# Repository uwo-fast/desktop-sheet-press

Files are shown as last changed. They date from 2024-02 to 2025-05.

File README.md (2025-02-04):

# Open Source Scientific Sheet Press: General Overview

This repository contains the design assets for the publication [Open-source cold and hot scientific sheet press for investigating polymer-based material properties](https://doi.org/10.1016/j.ohx.2024.e00566), which details the development of an adaptable, open-source platform for polymer sheet pressing.".

## Description

The Open Source Scientific Sheet Press is a mechanical device engineered for converting plastic waste into flat sheets of recycled plastic. Drawing inspiration from existing models like Precious Plastics, this platform is designed with adaptability, flexibility, and sustainability as core principles. This repository contains the main resources for the design of the physical press and it's manufacturing.

## Key Features

1. **Adaptability**: Engineered to work with a diverse range of plastic materials.
2. **Scalability**: Modular design allows for easy scaling to meet various production needs.
3. **Flexibility**: Utilizes open-source and off-the-shelf components, with comprehensive documentation and multiple system topologies for customization.

## General Applications

1. **Material Recycling**: Transforms plastic waste into reusable sheets.
2. **Product Manufacturing**: Ideal for the production of flat plastic components across various applications.
3. **Research and Development**: Serves as a testbed for material properties and novel production methods.

## Future Directions

1. **5x5' Canadian Standardized Sheet Press**: This version will meet industrial standards within the province of Ontario.
2. **Expanding System Topologies**: Work is ongoing to offer more system variations based on desired specifications and features.
3. **Vacuum Forming Integration**: Plans to incorporate vacuum forming capabilities, expanding the range of products that can be manufactured from the recycled plastic sheets.
4. **Automation and Industry 4.0**: Future iterations will focus on integrating smart technologies for autonomous operation, real-time data analytics, and IoT capabilities.
5. **Comprehensive Sourcing**: Plans to provide sourcing information tailored to various locales, considering regional regulations, standards, and availability.
6. **Reengineering High-Cost Components**: Long-term goal to redesign non-open-source and expensive components to meet required standards and certifications.

## Repository Structure

This repository will include multiple iterations and variations of the sheet press, acting as a living document for continuous development and enhancements.

For detailed documentation, consult the respective folders and files within this repository.

## About the FAST Research Group

The Free Appropriate Sustainable Technology (FAST) research group, led by Professor Joshua Pearce, is based at Western University and focuses on driving sustainability innovations. The group works on a myriad of projects ranging from solar photovoltaic technology to alternative food to open-source hardware to distributed recycling and additive manufacturing (DRAM).

This Open Source Sheet Press project is an initiative led by the FAST group, aligning with our broader goals of sustainable development and open-source technology. We are focused on developing solutions that not only contribute to recycling and sustainable manufacturing but also push the boundaries of what's possible through continuous research and innovation.

For more information on the FAST group, please visit [FAST on Appropedia](https://www.appropedia.org/FAST).

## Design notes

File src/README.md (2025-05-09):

# software

The main current functional software can be found in 'main' folder, see 'command_usage.md' and/or 'gui_usage' under the main 'docs' folder for operation instructions.

## Overview

Dual channel PID temperature controller. Can be operated as two independent loops or cascaded.

## Important Notes

### Safeguard against NaN

Safeguard against NaN (Not a Number) outputs from PID controllers, which can occur if the temperature sensor provides invalid readings. This occurs every once in a while with the MAX31855 thermocouple amplifier.If the PID output is NaN, perform a bumpless reset by:

1. Switching the PID controller to MANUAL mode to halt automatic control.
2. Resetting the output to 0 to ensure no erroneous signals are sent to actuators.
3. Switching back to AUTOMATIC mode to reinitialize the PID controller's internal state.

This prevents the NaN value from persisting and propagating through subsequent control cycles.

### Generic Software Work

Currently the software from this project is no longer under development and future development efforts are being continued at [uwo-fast/OpenTempControl](https://github.com/uwo-fast/OpenTempControl)

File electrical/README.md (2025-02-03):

# Electrical

## Attribution

https://github.com/adafruit/MicroSD-breakout-board

https://github.com/botbotty/Nano_KiCAD

https://github.com/adafruit/Adafruit-MAX31855-breakout-board

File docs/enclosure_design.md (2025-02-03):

# Electrical Enclosure CAD

THe CAD for the electrical enclosure was made using Onshape by Morgan C. Woods: [Electrical Enclosure - Desktop Sheet Press](https://cad.onshape.com/documents/9d69c9f84549b53a6491ef35/w/14b6a93e6542961346169c7c/e/4beb3684347d9fde3d54fadf).

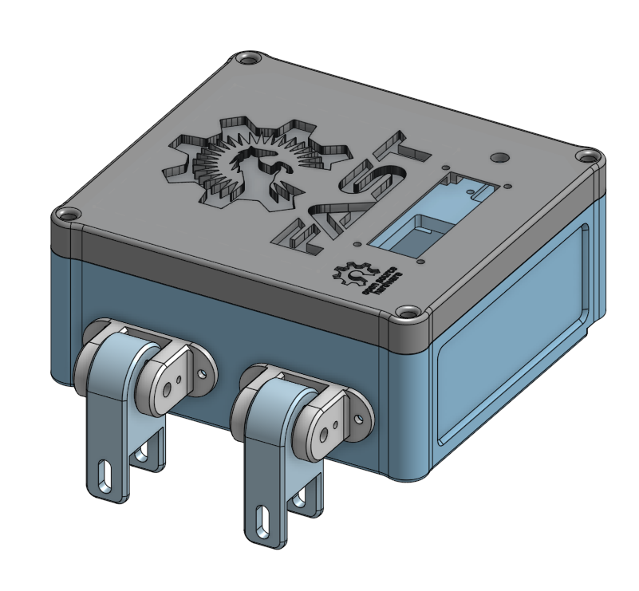
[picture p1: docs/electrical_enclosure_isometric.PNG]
Isometric View of the Electrical Enclosure

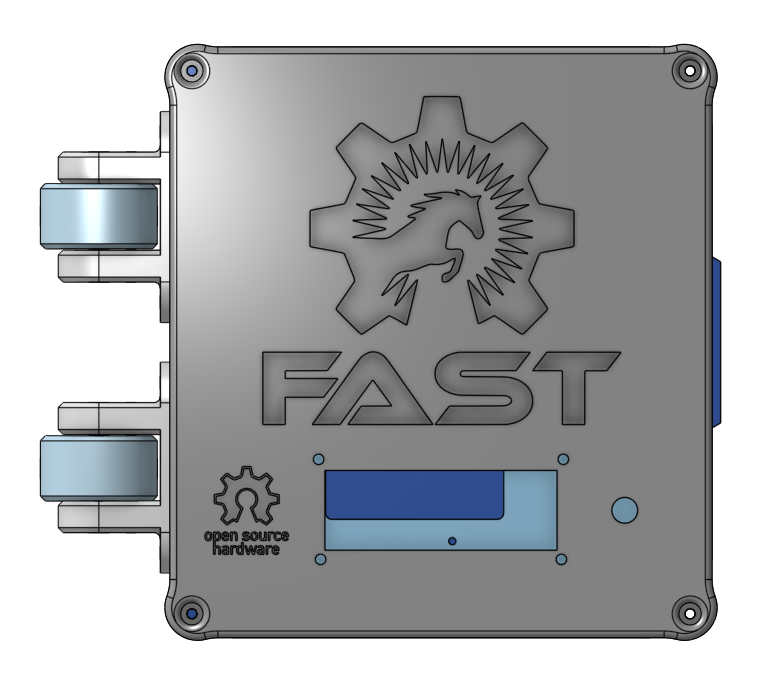
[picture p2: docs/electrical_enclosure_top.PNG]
Top View of the Electrical Enclosure


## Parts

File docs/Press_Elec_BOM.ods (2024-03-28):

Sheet: Paper_Rev0
 |  |  |  | Total | $880.58 | Tot. - RE | $375.38
Item # | Component Designator | Description | Number | Cost per unit CAD | Total cost CAD | Source of materials | Material type
36 | Flat Heating Element | 125W, 120V, Steel Strip Heater | 8.00 | $63.15 | $505.20 | Omega (https://www.omega.ca/en/industrial-heaters/strip-heaters/msh/p/MSH00007) | Rust-resistance Steel, Mica Insulation
37 | Arduino Nano | Nano V3.0 R3 Microcontroller Board | 0.33 | $39.99 | $13.33 | Amazon (https://www.amazon.ca/ELEGOO-Arduino-ATmega328P-Without-Compatible/dp/B0713XK923/) | Electronics
38 | Thermocouple sensor | Fine Diameter Thermocouple Probes | 2.00 | $50.97 | $101.94 | Omega (https://www.omega.ca/en/temperature-measurement/temperature-probes/probes-with-lead-wires/fast-mi-tc/p/TJM-CA310-M100U-150) | 310 Stainless Steel, PFA Insulation
39 | Thermocouple amplifier | MAX31855 Break out | 2.00 | $14.95 | $29.90 | Adafruit (https://www.adafruit.com/product/269) | Electronics
40 | Solid State Relay | SSR RELAY SPST-NO 10A 24-280V | 2.00 | $30.04 | $60.08 | Digikey (https://www.digikey.ca/en/products/detail/altran-magnetics-llc/ASR-SIM240D10ZW-LQ/14553491) | Silicon, epoxy, aluminum
41 | Hook-up Wire | 14 AWG, 100ft Wire | 0.50 | $72.55 | $36.28 | Mouser (https://www.mouser.ca/ProductDetail/Alpha-Wire/541419-GR005?qs=G7mWZQZ8fQl1gNz6Gz27bw%3D%3D) | Copper, PVC
42 | Male Blade Terminal | Terminals 16-14 Nylon Insulated Male Quick Connect | 10.00 | $0.15 | $1.50 | Mouser (https://www.mouser.ca/ProductDetail/Mueller-Electric/AI-50181N?qs=rQFj71Wb1eWmiZF%252BkWw8Ig%3D%3D) | Tin-plated Brass, Nylon
43 | Female Blade Terminal | Terminals 16-14 Fully Nylon Insulated Female Quick Connect | 10.00 | $0.15 | $1.53 | Mouser (https://www.mouser.ca/ProductDetail/Mueller-Electric/AI-50209?qs=rQFj71Wb1eUSkyk1RbYImw%3D%3D) | Tin-plated Brass, Nylon
44 | High-Temperature Hook-up Wire | High-Temperature Stranded Wire with Fiberglass Outer and Mica Inner Insulation, 18 Gauge; Length, ft. 50 | 0.20 | $85.50 | $17.10 | McMaster (https://www.mcmaster.com/heater-wire/maximum-temperature~840-f/) | Tin-plated Copper, Fiberglass, Mica, PTFE
45 | Circuit Breaker | Mode: W28-XQ1A-14, 14A, Thermal type Circuit Breaker | 1.00 | $7.44 | $7.44 | Digikey (https://www.digikey.ca/en/products/detail/te-connectivity-potter-brumfield-relays/W28-XQ1A-14/1128430) | Copper/Silver, Thermoset Polymer
46 | Metric Screws & Nuts | VIGRUE 1080Pcs Metric Socket Head Screws, Bolts, Nuts, Washers Kit | 0.02 | $29.00 | $0.54 | Amazon (https://www.amazon.ca/VIGRUE-M2-M3-M4-1080PCS-Stainless-Screws-Socket/dp/B07FCDL2SY/) | Alloy Steel
47 | AC Power Cord | 14AWG NEMA5-15P - IEC320 3' Power Cord | 1.00 | $12.91 | $12.91 | Digikey (https://www.digikey.ca/en/products/detail/tripp-lite/P007-003/5359145) | Copper, PVC
48 | Power Entry Recipticle | AC Power Entry Modules IEC-320 C-14 | 1.00 | $16.59 | $16.59 | Mouser (https://www.mouser.ca/ProductDetail/TE-Connectivity-PB/15CE1?qs=4aYpRZv1C8L8%2FzM5tPK%252BSA%3D%3D) | Copper/Silver, Thermoset Polymer
49 | Jumper Wires | 120pcs Multicolored Dupont Wire 40pin | 0.13 | $15.99 | $2.00 | Amazon (https://www.amazon.ca/Elegoo-120pcs-Multicolored-Breadboard-arduino/dp/B01EV70C78/) | Copper, PVC, ABS
50 | LCD Display | SunFounder IIC/I2C/TWI 1602 Serial LCD | 1.00 | $13.59 | $13.59 | Amazon (https://www.amazon.ca/SunFounder-Serial-Module-Display-Arduino/dp/B019K5X53O/?th=1) | Electronics
51 | Rotary Encoder Dial | Model KY-040, 5V, 20 PPR Rotary Encoder Dial | 0.20 | $17.40 | $3.48 | Amazon (https://www.amazon.ca/Cylewet-Encoder-15%C3%9716-5-Arduino-CLT1062/dp/B07DFFSZ73) | Electronics
52 | AC/DC Converter | PSK-5D-9 – AC/DC Module | 1.00 | $9.80 | $9.80 | Mouser (https://www.mouser.ca/ProductDetail/CUI-Inc/PSK-5D-9?qs=DRkmTr78QAS7xBfnsfADZA%3D%3D) | Electronics
53 | SD Card | SAMSUNG EVO Select Micro SD-Memory-Card | 1.00 | $20.05 | $20.05 | Amazon (https://www.amazon.ca/SAMSUNG-Plus-128GB-MB-ME128KA-AM/dp/B09B1JFY24?th=1) | Electronics
54 | SD Card Reader | Adafruit MicroSD breakout board PCB | 1.00 | $10.68 | $10.68 | Digi Key (https://www.digikey.ca/en/products/detail/adafruit-industries-llc/254/5761230) | Electronics
55 | Wire Splice Connector | TE Connectivity Electro Tap Connetor 1-to-2 wire splitter | 2.00 | $1.28 | $2.56 | Mouser (https://www.mouser.ca/ProductDetail/TE-Connectivity/735398?qs=sd1rtLGwt44IW6QwNSGZLw%3D%3D) | Electronics
56 | Tie Plate | Simpson Strong-Tie TP 3-1/8-in x 5-in 20-Gauge Galvanized Tie Plate | 1.00 | $2.49 | $2.49 | Lowes (https://www.lowes.ca/product/straps-ties/simpson-strong-tie-tp-3-18-in-x-5-in-20-gauge-galvanized-tie-plate-94135) | Galvanized Steel
57 | PETG Filament | Polymaker PETG Filament 1.75mm, ]1kg | 0.40 | $28.99 | $11.60 | Amazon (https://www.amazon.ca/Polymaker-Filament-1-75mm-Strong-Printer/dp/B0CB8C891M/?th=1) | Galvanized Steel
58 |  |  |  |  | $0.00
59 |  |  |  |  | $0.00

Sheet: v3
Bill of materials |  |  | Project name: | RH Mini Press
Part # | Common Name | Product Name | Number of products to buy | Cost/Product | Total Cost | URL | Special instructions | Ordered | Received | Set
1 | Braided Sleeving | Techflex® Insultherm® Tru-Fit Braided Fiberglass Sleeving | 0.12 | 64.66 | 7.7592 | https://www.cabletiesandmore.ca/insultherm-tru-fit-sleeving | 3/8" dia, 50' long | 1 | 0 | 0
2 | Thermocouple Temperature Sensor | 240-080 – THERMOCOUPLE WIRE K-TYPE 1M | 4 | 15.63 | 62.52 | https://www.digikey.ca/en/products/detail/digilent-inc/240-080/5418219 |  | 1 | 1 | 0
3 | Solid State Relay | SSR: ASR-SIM240D25RW-LQ | 2 | 29.1 | 58.2 | https://www.digikey.ca/en/products/detail/altran-magnetics-llc/ASR-SIM240D25RW-LQ/14553471 |  | 1 | 1 | 0
4 | Power Entry Recipticle | AC Power Entry Modules IEC-320 C-14 | 1 | 16.59 | 16.59 | https://www.mouser.ca/ProductDetail/TE-Connectivity-PB/15CE1?qs=4aYpRZv1C8L8%2FzM5tPK%252BSA%3D%3D |  | 1 | 1 | 0
5 | Heat Sink | ???? | 2 | 1.31 | 2.62 | https://www.mouser.ca/ProductDetail/CUI-Devices/HSB24-252510?qs=t7xnP681wgWWLZ01VB4mNg%3D%3D |  | 1 | 1 | 0
6 | Wire | Hook-up Wire 541419 GREEN 100 FT | 1 | 72.55 | 72.55 | https://www.mouser.ca/ProductDetail/Alpha-Wire/541419-GR005?qs=G7mWZQZ8fQl1gNz6Gz27bw%3D%3D |  | 1 | 1 | 0
7 | I2C Converter | LCD Display I2C Interface | 1 | 2.47 | 2.47 | https://www.pcboard.ca/iic-i2c-serial-interface-for-lcd |  | 1 | 1 | 0
8 | Male Blade Terminal | Terminals 16-14 Nylon Insulated .250 X 0.032 Male Quick Connect | 10 | 0.15 | 1.5 | https://www.mouser.ca/ProductDetail/Mueller-Electric/AI-50181N?qs=rQFj71Wb1eWmiZF%252BkWw8Ig%3D%3D |  | 1 | 1 | 0
9 | Female Blade Terminal | Terminals 16-14 Fully Nylon Insulated .250 X 0.032 Female Quick Conn | 10 | 0.153 | 1.53 | https://www.mouser.ca/ProductDetail/Mueller-Electric/AI-50209?qs=rQFj71Wb1eUSkyk1RbYImw%3D%3D |  | 1 | 1 | 0
10 | High-Temperature Wire | High-Temperature Wire | 0.3 | 85.5 | 25.65 | https://www.mcmaster.com/heater-wire/maximum-temperature~840-f/ |  | 1 | 1 | 0
11 | Circuit Breaker | 14A Circuit breaker: W28-XQ1A-14 | 1 | 7.444 | 7.444 | https://www.digikey.ca/en/products/detail/te-connectivity-potter-brumfield-relays/W28-XQ1A-14/1128430 |  | 1 | 1 | 0
12 | Rotary Encoder Dial | Rotary Encoder – PEC12R-4215F-S0024 | 1 | 2.153 | 2.153 | https://www.digikey.ca/en/products/detail/bourns-inc/PEC12R-4215F-S0024/6153388 |  | 1 | 1 | 0
13 | AC Power Cord | CORD 14AWG NEMA5-15P - IEC320 3' | 1 | 12.91 | 12.91 | https://www.digikey.ca/en/products/detail/tripp-lite/P007-003/5359145 |  | 1 | 1 | 0
14 | Thermistor Lug Connection | NTC ASSEMBLY, LUG TERMINAL, 50K/ | 1 | 11.31 | 11.31 | https://www.digikey.ca/en/products/detail/tdk-corporation/NTCGP3UH503HCZCCA/11493113 |  | 1 | 0 | 0
15 | Flat Heating Element | Steel Strip Heater Mica insulated | 8 | 63.15 | 505.2 | https://www.omega.ca/en/industrial-heaters/strip-heaters/msh/p/MSH00007 |  | 1 | 1 | 1
16 | Arduino Terminal Adapter | 3pcs Expansion Board Terminal Adapter Shield for Arduino Nano | 0.3333333333 | 15.99 | 5.329999999467 | https://www.amazon.ca/KeeYees-Expansion-Terminal-Adapter-ATMEGA328P-AU/dp/B07YTZSR72 |  | 1 | 1 | 0
17 | Arduino Nano | Nano V3.0 R3 Microcontroller Compatible Board, ATMEGA328P-20AU | 1 | 12.95 | 12.95 | https://www.pishop.ca/product/atmega328p-au-arduino-compatible-nano-v3-0-r3-board/ |  | 1 | 1 | 0
18 |  |  |  |  | 0 |  |  | 0 | 1 | 0
19 |  |  |  |  | 0 |  |  | 0 | 1 | 0
20 | https://www.digikey.ca/en/products/detail/altran-magnetics-llc/ASR-SIM240D10ZW-LQ/14553491 |  |  |  | 0 |  |  | 0 | 1 | 0
21 | https://www.mouser.ca/ProductDetail/Newhaven-Display/NHD-0420D3Z-NSW-BBW-V3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 |  |  |  | 0 |  |  | 0 | 1 | 0
22 | https://www.sparkfun.com/products/15164 |  |  |  | 0 |  |  | 0 | 1 | 0
23 |  |  |  |  | 0 |  |  | 0 | 1 | 0
24 |  |  |  |  | 0 |  |  | 0 | 1 | 0
25 |  |  |  |  | 0 |  |  | 0 | 1 | 0
26 |  |  |  |  | 0 |  |  | 0 | 1 | 0
27 |  |  |  |  | 0 |  |  | 0 | 1 | 0
28 |  |  |  |  | 0 |  |  | 0 | 1 | 0
29 |  |  |  |  | 0 |  |  | 0 | 1 | 0
30 |  |  |  |  | 0 | sub. elements |  | 0 | 1 | 0
Total |  |  |  |  | 808.6862 | 303.4862
Tool # | - | - | - | -
1
2 |  | Solder Wire 63/37 Tin/Lead | 1 | 13.99 | 13.99 | https://www.amazon.ca/SainSmart-Sn63Pb37-Electrical-Soldering-0-22lbs/dp/B07PDC2D85
3 |  |  |  |  | 0
4 |  |  |  |  | 0
5 |  |  |  |  | 0
6 |  |  |  |  | 0
7 |  |  |  |  | 0
8 |  |  |  |  | 0
9 |  |  |  |  | 0
10 |  |  |  |  | 0

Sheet: v2
Bill of materials |  |  | Project name: | RH Mini Press
Part # | Common Name | Product Name | Number of products to buy | Cost/Product | Total Cost | URL | Special instructions
1 | Thermocouple board | Thermocouple Amplifier MAX31855 breakout board (MAX6675 upgrade) | 5 | 14.95 | 74.75 | https://www.adafruit.com/product/269
2 | Solid State Relay: ASR-SIM240D25RW-LQ |  | 2 | 29.1 | 58.2 | https://www.digikey.ca/en/products/detail/altran-magnetics-llc/ASR-SIM240D25RW-LQ/14553471
3 | AC Power Entry Modules IEC-320 C-14 | 592-15CE1 | 4 | 16.59 | 66.36 | https://www.mouser.ca/ProductDetail/TE-Connectivity-PB/15CE1?qs=4aYpRZv1C8L8%2FzM5tPK%252BSA%3D%3D
4 | Fan 40mm Noctua | Noctua NF-A4x10 5V, Premium Quiet Fan, 3-Pin, 5V Version (40x10mm, Brown) | 2 | 18.95 | 37.9 | https://www.amazon.ca/noctua-NF-A4x10-5V-3-Pin-Premium/dp/B00NEMGCIA
5 | Heat sink, BGA, 25x25x10 | 179-HSB24-252510 | 10 | 1.31 | 13.1 | https://www.mouser.ca/ProductDetail/CUI-Devices/HSB24-252510?qs=t7xnP681wgWWLZ01VB4mNg%3D%3D
6 | Ambient Temp Sensor | Grove - Temperature Sensor | 5 | 2.75 | 13.75 | https://www.seeedstudio.com/Grove-Temperature-Sensor.html
7 |  |  |  |  | 0
8 |  |  |  |  | 0
9 |  |  |  |  | 0
10 |  |  |  |  | 0
11 |  |  |  |  | 0
12 |  |  |  |  | 0
13 |  |  |  |  | 0
14 |  |  |  |  | 0
15 |  |  |  |  | 0
16 |  |  |  |  | 0
17 |  |  |  |  | 0
18 |  |  |  |  | 0
19 |  |  |  |  | 0
20 |  |  |  |  | 0
21 |  |  |  |  | 0
22 |  |  |  |  | 0
 |  |  |  |  | 264.06

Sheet: v1
Bill of materials |  |  | Project name: | RH Mini Press
Part # | Common Name | Product Name | Number of products to buy | Cost/Product | Total Cost | URL | Special instructions
1 |  | CONN TERM RCPT 10-14AWG CRIMP – 42868-2 | 100 | 0.171 | 17.1 | https://www.digikey.ca/en/products/detail/te-connectivity-amp-connectors/42868-2/2046708
2 | AC/DC Converter | PSK-5D-9 – AC/DC Module 9V 5W | 6 | 9.8 | 58.8 | https://www.mouser.ca/ProductDetail/CUI-Inc/PSK-5D-9?qs=DRkmTr78QAS7xBfnsfADZA%3D%3D
3 |  | 240-080 – THERMOCOUPLE WIRE K-TYPE 1M | 15 | 15.63 | 234.45 | https://www.digikey.ca/en/products/detail/digilent-inc/240-080/5418219
4 |  | 14A Circuit breaker: W28-XQ1A-14 | 3 | 7.444 | 22.332 | https://www.digikey.ca/en/products/detail/te-connectivity-potter-brumfield-relays/W28-XQ1A-14/1128430
5 |  | Solid State Relay: ASR-SIM240D25RW-LQ | 2 | 29.1 | 58.2 | https://www.digikey.ca/en/products/detail/altran-magnetics-llc/ASR-SIM240D25RW-LQ/14553471
6 |  | Performix 11201-6PK Plasti Dip Red Multi-Purpose Rubber Coating Aerosol - 11 oz, (Pack of 6) | 1 | 99.99 | 99.99 | https://www.amazon.ca/Plasti-Dip-11203-Multi-Purpose-Aerosol-11/dp/B00E975LQ8?hvadid=292918712370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
7 |  | Rotary Encoder – PEC12R-4215F-S0024 | 10 | 2.153 | 21.53 | https://www.digikey.ca/en/products/detail/bourns-inc/PEC12R-4215F-S0024/6153388
8 |  | Thermocouple Amplifier MAX31855 breakout board | 10 | 20.63 | 206.3 | https://www.mouser.ca/ProductDetail/Adafruit/269?qs=GURawfaeGuBvybki3upSHQ%3D%3D
9 |  | Hook-up Wire 541419 GREEN 100 FT | 1 | 72.55 | 72.55 | https://www.mouser.ca/ProductDetail/Alpha-Wire/541419-GR005?qs=G7mWZQZ8fQl1gNz6Gz27bw%3D%3D
10 |  | LCD Display I2C Interface | 5 | 2.47 | 12.35 | https://www.pcboard.ca/iic-i2c-serial-interface-for-lcd
11 | Male Blade Terminal | Terminals 16-14 Nylon Insulated .250 X 0.032 Male Quick Connect | 100 | 0.15 | 15 | https://www.mouser.ca/ProductDetail/Mueller-Electric/AI-50181N?qs=rQFj71Wb1eWmiZF%252BkWw8Ig%3D%3D
12 | Male Blade TerminalFem | Terminals 16-14 Fully Nylon Insulated .250 X 0.032 Female Quick Conn | 100 | 0.153 | 15.3 | https://www.mouser.ca/ProductDetail/Mueller-Electric/AI-50209?qs=rQFj71Wb1eUSkyk1RbYImw%3D%3D
13 | High-Temperature Wire | High-Temperature Wire | 1 | 85.5 | 85.5 | https://www.mcmaster.com/heater-wire/maximum-temperature~840-f/ | 50ft, AWG 18
14 | Ring Connector | CONN RING CIRC 10-12AWG #10 | 50 | 0.243 | 12.15 | https://www.digikey.ca/en/products/detail/te-connectivity-amp-connectors/33457/149318
15 | AC Power Recepticle | PWR ENT MOD RCPT IEC320-C14 PNL | 2 | 20.19 | 40.38 | https://www.digikey.ca/en/products/detail/te-connectivity-corcom-filters/1-1609112-3/2292075
16 | AC Power Cord | CORD 14AWG NEMA5-15P - IEC320 3' | 2 | 12.91 | 25.82 | https://www.digikey.ca/en/products/detail/tripp-lite/P007-003/5359145
17 | Arduino Terminal Adapter | 3pcs Expansion Board Terminal Adapter Shield for Arduino Nano | 1 | 15.99 | 15.99 | https://www.amazon.ca/KeeYees-Expansion-Terminal-Adapter-ATMEGA328P-AU/dp/B07YTZSR72
18 |  |  |  |  | 0
19 |  |  |  |  | 0
20 |  |  |  |  | 0
21 |  |  |  |  | 0
22 |  |  |  |  | 0
23 |  |  |  |  | 0
24 |  |  |  |  | 0
25 |  |  |  |  | 0
 |  |  |  |  | 1013.742

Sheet: SSR
Table 1: Product Features |  |  | Time |  | Freq
Feature | Specification |  | 1ms | 0.001 | 1000
Switching Mode | Zero-crossing or Random-on |  | 10ms | 0.01 | 100
Rated Load Current | 10A, 16A, 25A
LED Indication | With LED
Internal RC Protection Circuit | Included
MOV Protection (Optional) | Available
Packaging (Bulk) | -
Packaging (Individual) | Y
Table 2: SIM Series Options
Option | Code | Value
Load Voltage | 240 | 240VAC
 | 380 | 380VAC
Control Voltage Type | D | DC
Load Current | 10 | 10Amp
 | 16 | 16Amp
 | 25 | 25Amp
Switching Mode | Z | Zero Crossing
 | R | Random-on
Control Voltage | W | 4-32VDC
LED Indication | Blank | Without
 | L | With LED
Terminal Type | Blank | Screw
 | Q | Quick Connection
Table 3: Technical Specification - Input Circuit
Specification | Value
Control Voltage Range (W) | 4-32VDC
Must Turn-on Voltage | 4VDC
Must Turn-off Voltage | 1VDC
Maximum Input Current | 25mA
Table 4: Technical Specification - Output Circuit
Specification | 240VAC | 380VAC
Load Voltage Range | 24-280VAC | 24-440VAC
Maximum Turn-On Time (Random-on) | 1ms | 1ms
Maximum Turn-On Time (Zero Crossing) | 10ms | 10ms
Maximum Turn-Off Time | 10ms | 10ms
Maximum Surge Current [@10 ms] | 10A: 100A | 16A: 160A
 | 16A: 160A | 25A: 250A
 | 25A: 250A
Table 5: General Information
Specification | Value
Dielectric Strength (50/60Hz) | Input/Output: 4000Vrms
 | Input,Output/Base: 2500Vrms
Power Factor | >0.5
Ambient Operating Temperature Range | -30°C to +80°C
Ambient Storage Temperature Range | -30°C to +100°C
Weight (Typical) | 35g

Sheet: ALL
Bill of materials |  |  | Project name: | RH Mini Press
Part # | Common Name | Product Name | Number of products to buy | Cost/Product | Total Cost | URL | Special instructions
1 |  | CONN TERM RCPT 10-14AWG CRIMP – 42868-2 | 100 | 0.171 | 17.1 | https://www.digikey.ca/en/products/detail/te-connectivity-amp-connectors/42868-2/2046708
3 |  | 240-080 – THERMOCOUPLE WIRE K-TYPE 1M | 15 | 15.63 | 234.45 | https://www.digikey.ca/en/products/detail/digilent-inc/240-080/5418219
4 |  | 14A Circuit breaker: W28-XQ1A-14 | 3 | 7.444 | 22.332 | https://www.digikey.ca/en/products/detail/te-connectivity-potter-brumfield-relays/W28-XQ1A-14/1128430
5 |  | Solid State Relay: ASR-SIM240D25RW-LQ | 2 | 29.1 | 58.2 | https://www.digikey.ca/en/products/detail/altran-magnetics-llc/ASR-SIM240D25RW-LQ/14553471
6 |  | Performix 11201-6PK Plasti Dip Red Multi-Purpose Rubber Coating Aerosol - 11 oz, (Pack of 6) | 1 | 99.99 | 99.99 | https://www.amazon.ca/Plasti-Dip-11203-Multi-Purpose-Aerosol-11/dp/B00E975LQ8?hvadid=292918712370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
8 |  | Thermocouple Amplifier MAX31855 breakout board | 10 | 20.63 | 206.3 | https://www.mouser.ca/ProductDetail/Adafruit/269?qs=GURawfaeGuBvybki3upSHQ%3D%3D
9 |  | Hook-up Wire 541419 GREEN 100 FT | 1 | 72.55 | 72.55 | https://www.mouser.ca/ProductDetail/Alpha-Wire/541419-GR005?qs=G7mWZQZ8fQl1gNz6Gz27bw%3D%3D
10 |  | LCD Display I2C Interface | 5 | 2.47 | 12.35 | https://www.pcboard.ca/iic-i2c-serial-interface-for-lcd
11 | Male Blade Terminal | Terminals 16-14 Nylon Insulated .250 X 0.032 Male Quick Connect | 100 | 0.15 | 15 | https://www.mouser.ca/ProductDetail/Mueller-Electric/AI-50181N?qs=rQFj71Wb1eWmiZF%252BkWw8Ig%3D%3D
12 | Male Blade TerminalFem | Terminals 16-14 Fully Nylon Insulated .250 X 0.032 Female Quick Conn | 100 | 0.153 | 15.3 | https://www.mouser.ca/ProductDetail/Mueller-Electric/AI-50209?qs=rQFj71Wb1eUSkyk1RbYImw%3D%3D
13 | High-Temperature Wire | High-Temperature Wire | 1 | 85.5 | 85.5 | https://www.mcmaster.com/heater-wire/maximum-temperature~840-f/ | 50ft, AWG 18
14 | Ring Connector | CONN RING CIRC 10-12AWG #10 | 50 | 0.243 | 12.15 | https://www.digikey.ca/en/products/detail/te-connectivity-amp-connectors/33457/149318
15 | AC Power Recepticle | PWR ENT MOD RCPT IEC320-C14 PNL | 2 | 20.19 | 40.38 | https://www.digikey.ca/en/products/detail/te-connectivity-corcom-filters/1-1609112-3/2292075
16 | AC Power Cord | CORD 14AWG NEMA5-15P - IEC320 3' | 2 | 12.91 | 25.82 | https://www.digikey.ca/en/products/detail/tripp-lite/P007-003/5359145
17 | Arduino Terminal Adapter | 3pcs Expansion Board Terminal Adapter Shield for Arduino Nano | 1 | 15.99 | 15.99 | https://www.amazon.ca/KeeYees-Expansion-Terminal-Adapter-ATMEGA328P-AU/dp/B07YTZSR72
18 |  |  |  |  | 0
19 |  |  |  |  | 0
20 |  |  |  |  | 0
21 |  |  |  |  | 0
22 |  |  |  |  | 0
23 |  |  |  |  | 0
24 |  |  |  |  | 0
25 |  |  |  |  | 0
 |  |  |  |  | 933.412

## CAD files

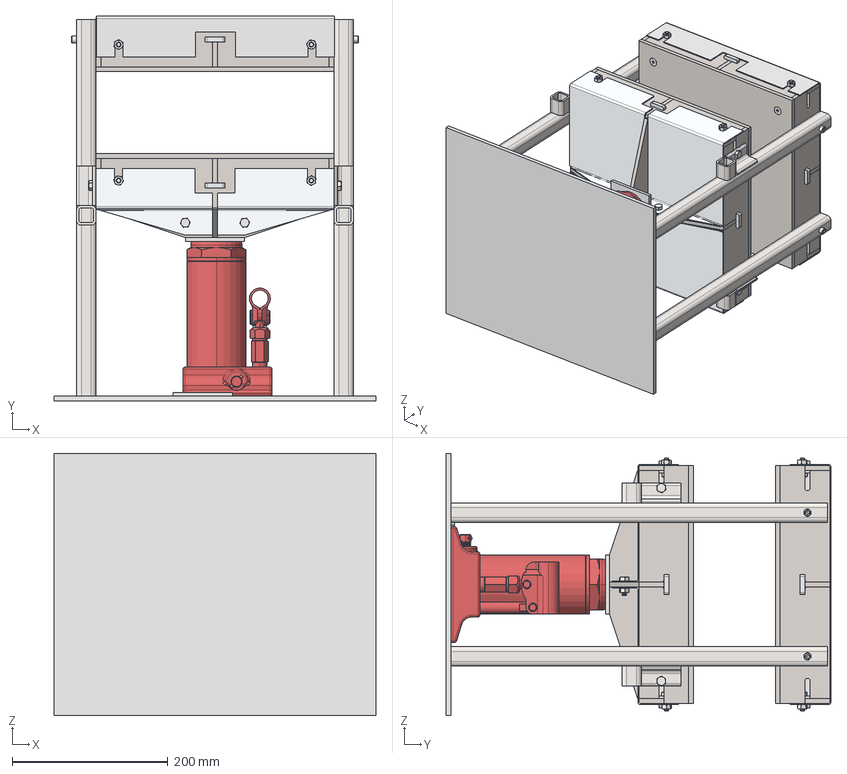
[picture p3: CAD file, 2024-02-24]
mechanical-design/structural/OSCHSSP_press_structural.FCStd
412.8 x 493.7 x 336.5 mm
Outer Framing Wall_Framing Rib - Toleranced
Outer Framing Wall_Framing Rib - Toleranced001
Outer Framing Wall_Framing Rib - Toleranced002
Outer Framing Wall_Framing Rib - Toleranced003
Steel Platen_Laser Cutting
Interlocking Tab_Interlock Toleranced
Interlocking Tab_Interlock Toleranced001
Interlocking Tab_Interlock Toleranced002
Interlocking Tab_Interlock Toleranced003
Center Support_Center Rib Toleranced
Center Support_Center Rib Toleranced001
Mounting Bracket_L1x1x0.125x1
Mounting Bracket_L1x1x0.125x002
Mounting Bracket_L1x1x0.125x003
Mounting Bracket_L1x1x0.125x004
hex bolt_ai_HBOLT 0.2500-20x0.75x0.75-S
hex bolt_ai_HBOLT 0.2500-20x0.75x0.75-S001
hex bolt_ai_HBOLT 0.2500-20x0.75x0.75-S002
hex bolt_ai_HBOLT 0.2500-20x0.75x0.75-S003
hex nut_ai_HNUT 0.2500-20-D-N
hex nut_ai_HNUT 0.2500-20-D-N001
hex nut_ai_HNUT 0.2500-20-D-N002
hex nut_ai_HNUT 0.2500-20-D-N003
socket countersunk head cap screw_ai_SCHCSCREW 0.25-20x0.875x0.875-HX-S
socket countersunk head cap screw_ai_SCHCSCREW 0.25-20x0.875x0.875-HX-S001
socket countersunk head cap screw_ai_SCHCSCREW 0.25-20x0.875x0.875-HX-S002
socket countersunk head cap screw_ai_SCHCSCREW 0.25-20x0.875x0.875-HX-S003
hex nut_ai_HNUT 0.2500-20-D-N004
hex nut_ai_HNUT 0.2500-20-D-N005
hex nut_ai_HNUT 0.2500-20-D-N006
hex nut_ai_HNUT 0.2500-20-D-N007
Sheet Metal Enclosure
Outer Framing Wall_Framing Rib - Toleranced004
Outer Framing Wall_Framing Rib - Toleranced005
Outer Framing Wall_Framing Rib - Toleranced006
Outer Framing Wall_Framing Rib - Toleranced007
Steel Platen_Laser Cutting001
Interlocking Tab_Interlock Toleranced004
Interlocking Tab_Interlock Toleranced005
Interlocking Tab_Interlock Toleranced006
Interlocking Tab_Interlock Toleranced007
Mounting Bracket_L1x1x0.125x005
Mounting Bracket_L1x1x0.125x006
Mounting Bracket_L1x1x0.125x007
Mounting Bracket_L1x1x0.125x008
hex bolt_ai_HBOLT 0.2500-20x0.75x0.75-S004
hex bolt_ai_HBOLT 0.2500-20x0.75x0.75-S005
hex bolt_ai_HBOLT 0.2500-20x0.75x0.75-S006
hex bolt_ai_HBOLT 0.2500-20x0.75x0.75-S007
hex nut_ai_HNUT 0.2500-20-D-N008
hex nut_ai_HNUT 0.2500-20-D-N009
hex nut_ai_HNUT 0.2500-20-D-N010
hex nut_ai_HNUT 0.2500-20-D-N011
socket countersunk head cap screw_ai_SCHCSCREW 0.25-20x0.875x0.875-HX-S004
socket countersunk head cap screw_ai_SCHCSCREW 0.25-20x0.875x0.875-HX-S005
socket countersunk head cap screw_ai_SCHCSCREW 0.25-20x0.875x0.875-HX-S006
socket countersunk head cap screw_ai_SCHCSCREW 0.25-20x0.875x0.875-HX-S007
hex nut_ai_HNUT 0.2500-20-D-N012
hex nut_ai_HNUT 0.2500-20-D-N013
hex nut_ai_HNUT 0.2500-20-D-N014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

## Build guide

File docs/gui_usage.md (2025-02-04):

# GUI Usage

The GUI is based on a 2x16 LCD and a button rotary encoder. The main screen displays the temperatures, set temperature, outputs, and remaining time, while the options screen allows user control over the process variables.

While on the main screen, click the button once to enter the options screen. This will place you on the top "Back" line, which can be single-clicked again to return to the main menu. In the options menu, you can use the encoder to scroll up or down and single-click the button to select a variable. Once a variable is selected, it can be incremented/decremented by scrolling the value using the encoder. Once you are done modifying the variable, single-click again to deselect the item and return to navigating the menu with the cursor.

The state line allows control over the states:

- In standby, click the state line once to start a new process.
- In any state, click and hold the state line to return to standby.
- In any state, double-click to skip the current state and force the next (not recommended for regular operation).

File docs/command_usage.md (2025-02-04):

# Command Usage

Make sure that your serial monitor is set to baud rate '115200' and termination to 'New Line'.

| Command | Description | Example |
| --- | --- | --- |
| `st=<value>` | Sets a new setpoint for all sensors. | `st=25.5` |
| `dt=<value>` | Sets a new duration for the process. | `dt=60` |
| `dt+<value>` | Increases the duration by the specified value. | `dt+15` |
| `dt-<value>` | Decreases the duration by the specified value. | `dt-10` |
| `rt=<value>` | Sets a new remaining duration for the process. | `rt=30` |
| `kp=<value>` | Sets a new proportional gain (Kp) for all sensors. | `kp=2.5` |
| `ki=<value>` | Sets a new integral gain (Ki) for all sensors. | `ki=0.1` |
| `kd=<value>` | Sets a new derivative gain (Kd) for all sensors. | `kd=0.01` |
| `prep` | Sets the machine state to preparing. | `prep` |
| `active` | Sets the machine state to active. | `active` |
| `term` | Sets the machine state to terminating. | `term` |
| `standby` | Sets the machine state to standby. | `standby` |
| `eeprom=reset` | Resets the EEPROM with a partial reset. | `eeprom=reset` |
| `eeprom=fullreset` | Resets the EEPROM with a full reset. | `eeprom=fullreset` |

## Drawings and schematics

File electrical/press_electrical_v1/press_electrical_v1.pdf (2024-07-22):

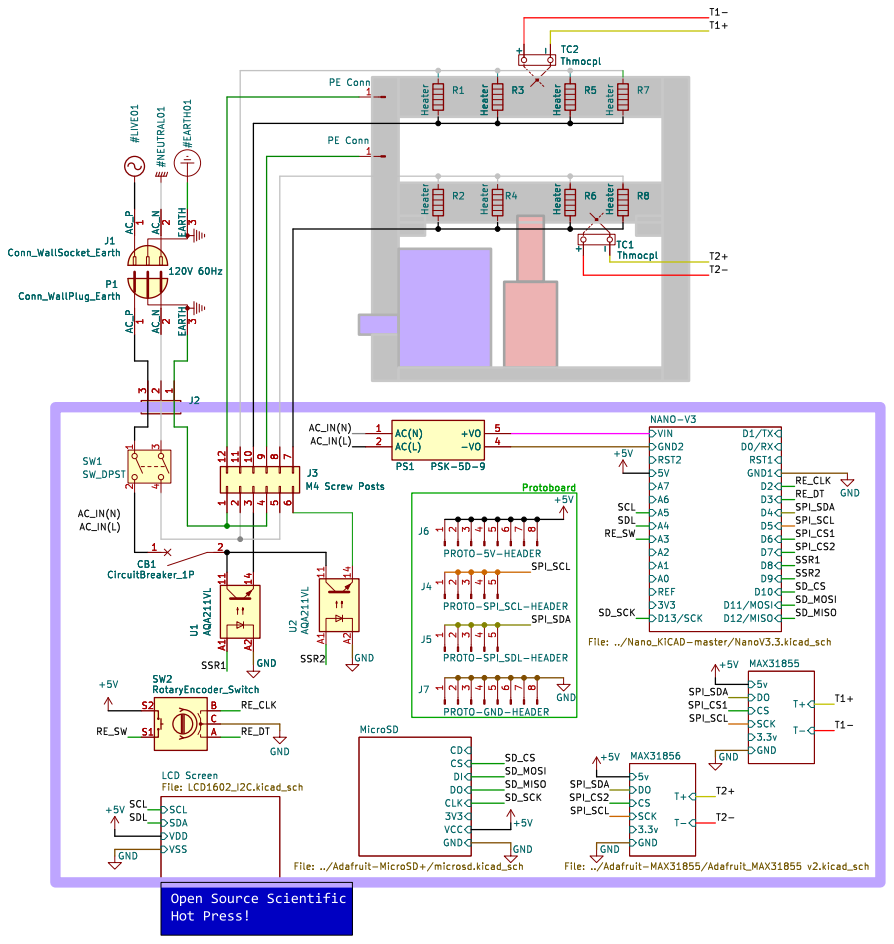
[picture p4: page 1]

File: ../Adafruit-MicroSD+/microsd.kicad_sch SCL SDA

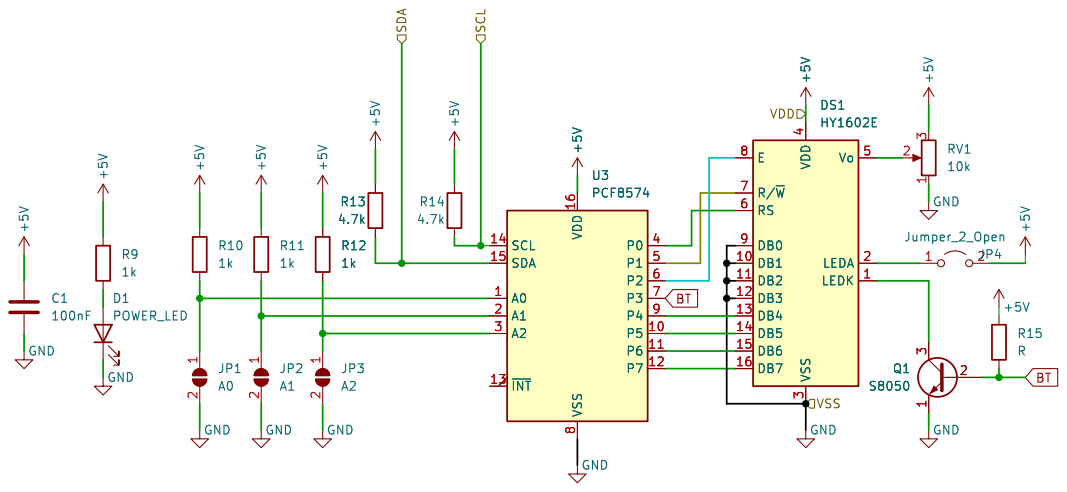
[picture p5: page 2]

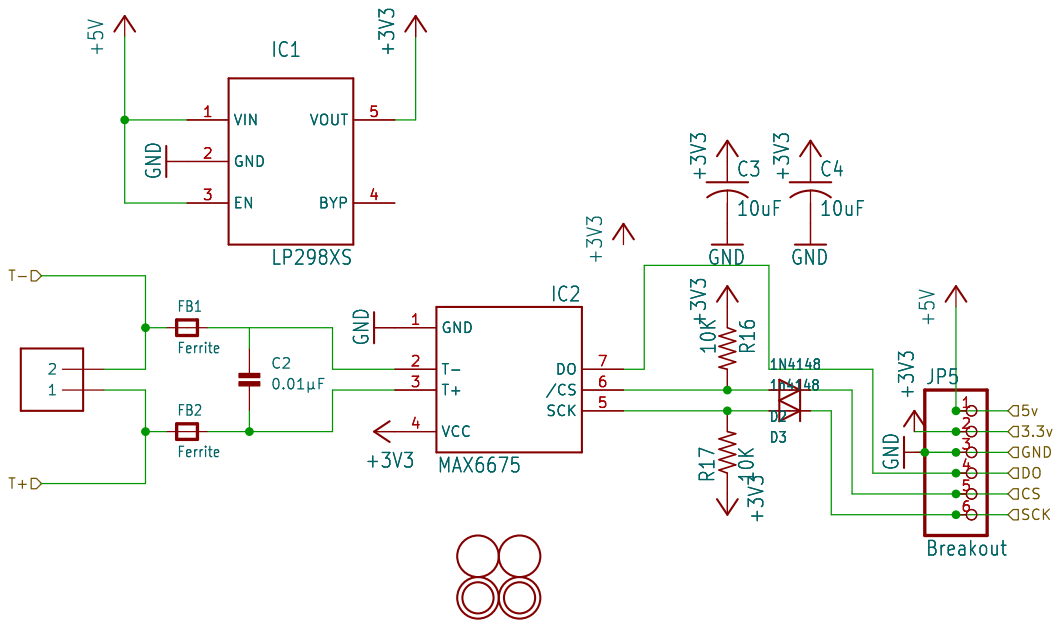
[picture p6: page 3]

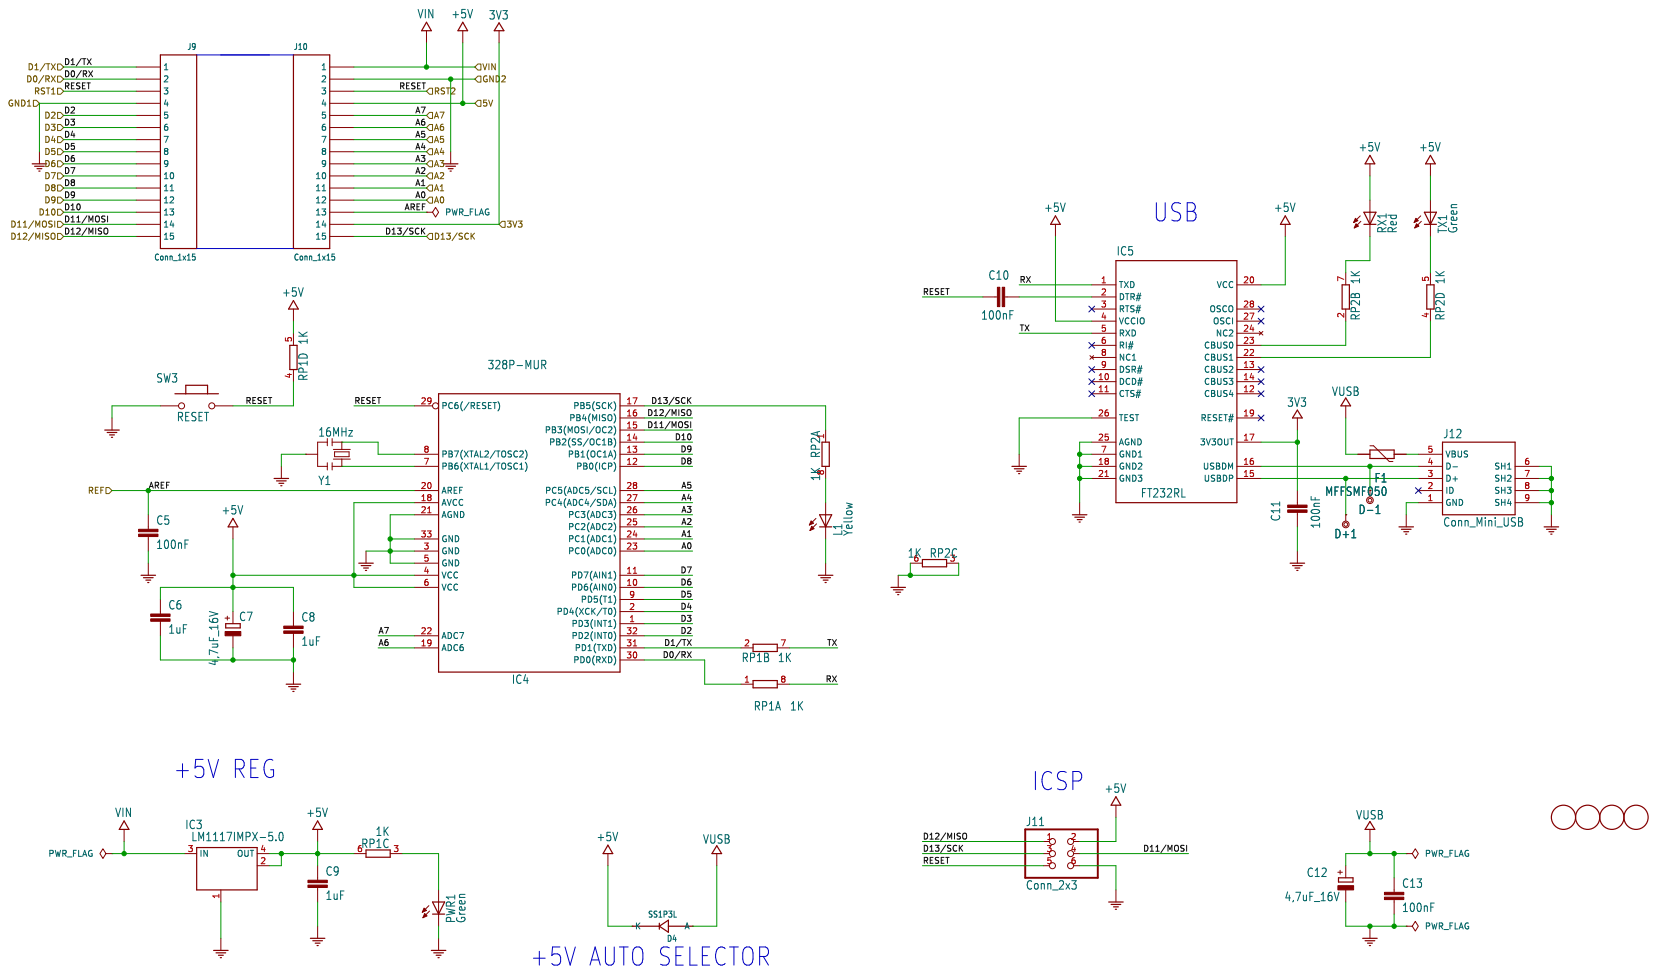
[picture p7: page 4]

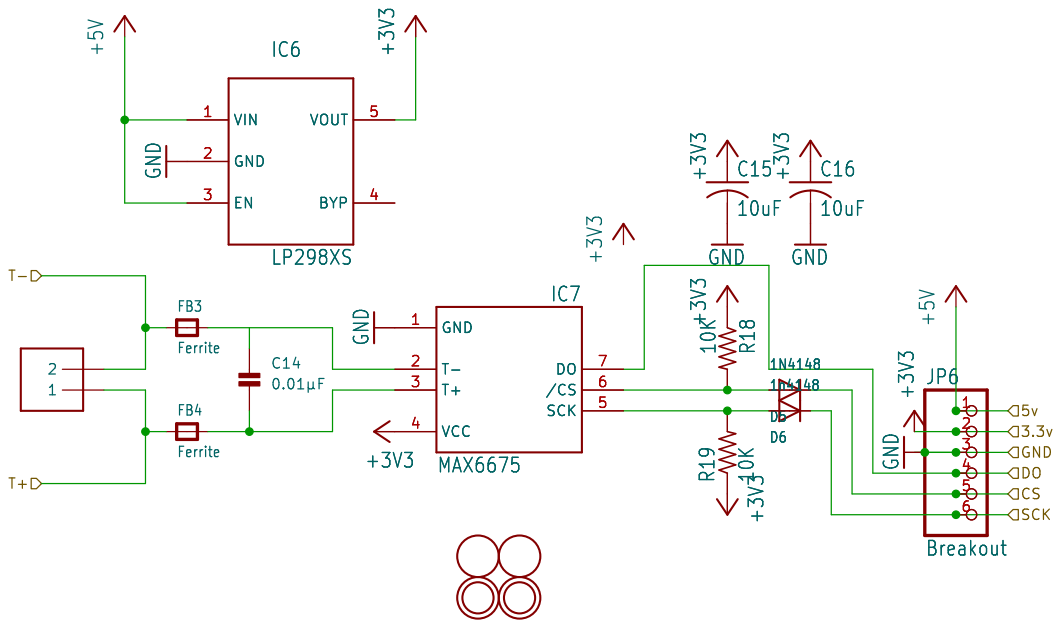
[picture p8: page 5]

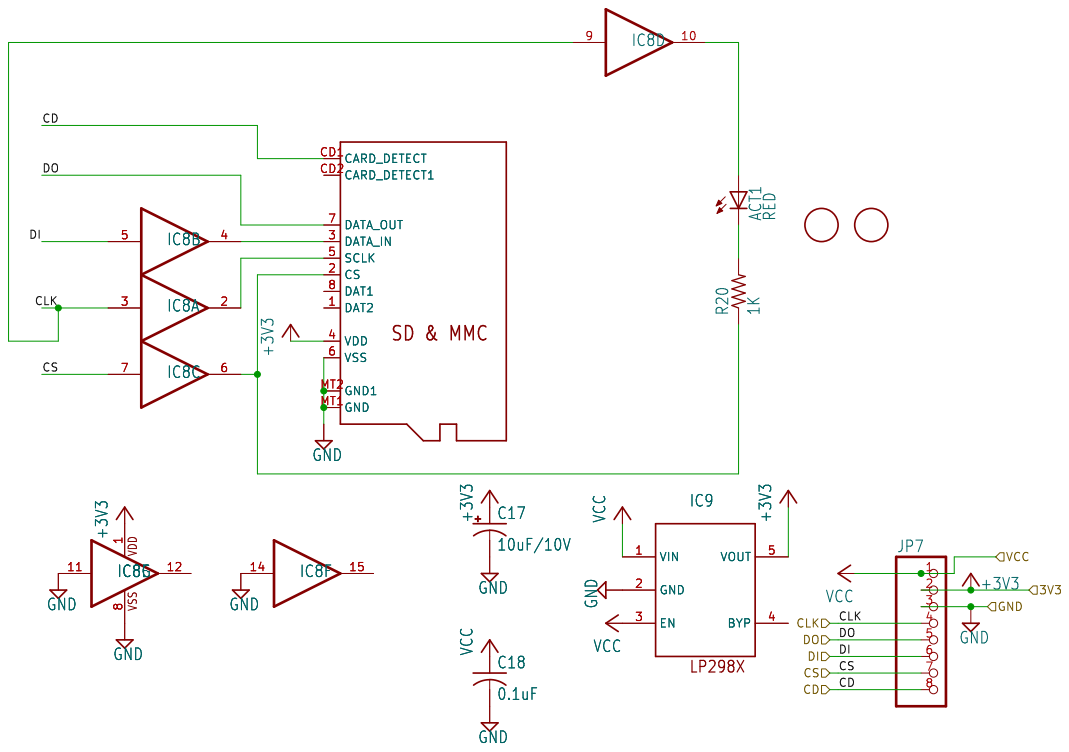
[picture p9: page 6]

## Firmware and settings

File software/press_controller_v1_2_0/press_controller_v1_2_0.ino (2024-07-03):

#define _PRESS_CONTROL_v1_1_0

/**********************************************************************************************
 *  \par        Press Controller - Source File.
 *
 *  \par        Details
 *  \par
 *              Press Controller v1 Firmware.
 *              This is the Arduino Code for the Open Source Cold Hot Scientific Sheet Press.
 *  \par
 *              You need to have the following libraries installed in your Arduino IDE :
 *               - [leave blank fill later with all the libraries]
 *
 *              This release has been tested with the following library versions:
 *              [lib]  Vxx.yy.zz
 *
 *  \file       press_controller_v1_1_0.ino
 *  \author     Cameron K. Brooks <https://www.appropedia.org/User:CameronBrooks11>
 *  \authors	Morgan C. Woods <https://www.appropedia.org/User:M.Woods>
 * 					- First author of the research paper for which this code was prepared.
 * 				Joshua M. Pearce <https://www.appropedia.org/User:J.M.Pearce>
 *  					-  Supervising Professor for the research paper for which this code was prepared.
 *  \authors
 *  		    Marc Schönfleisch <http://malectrics.eu/>
 * 					- The creator of Arduino_Spot_Welder_V4_0_2.ino <https://github.com/KaeptnBalu/Arduino_Spot_Welder_V4>.
 * 					- Served as a key reference for the development of this code.
 *
 *  \version    1.1.0
 *  \date       Mar 2024
 *  \copyright  Copyright(c) 2024 Marc Schönfleisch <info@malectrics.eu>.
 *  \copyright  Copyright(c) 2024 Cameron K. Brooks <cambrooks3393@gmail.com>.
 *
 *  \par        Changelog
 *  \li         2024-MM-DD  -  Initial release
 *
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
 *
 */
/***********************************************************************************************/

/***********************************************************************************************
 *  \par        Menu and display Screen Descriptions.
 *              The menus and dispay screens are arranged as follows;
 *  \verbatim
 *  \todo
 * 	INSERT HERE FRON THE SHEET : https://docs.google.com/spreadsheets/d/1ETsrqTxRlOqclLa2pnuBXwNIZhDpUWXC6jgvGGqIkTA/edit?usp=sharing
 *
 *  \endverbatim
 */
/***********************************************************************************************/

#include "press_controller_v1_2_0.h"

#include <SPI.h>
#include <Wire.h>
#include <avr/wdt.h>

#include <SD.h>

// The EEPROM library, this is for storing data in the EEPROM memory aka non-volatile memory
#include <EEPROM.h>

// The PROGMEM library, this is for storing data in the program memory aka flash memory
#include <avr/pgmspace.h>

#include <PID_v1.h>
#include <Adafruit_MAX31855.h>

#ifdef _LCDGUI_
// The I2C LCD library
#include <LiquidCrystal_I2C.h>
// The menu wrapper library
#include <LiquidMenu.h>

// For Rotary Click Encoder
#include <ClickEncoder.h>
#include <TimerOne.h>
#endif /* _LCDGUI_ */

/***************************************************************************************************
 * Global program variables and objects                                                             *
 ***************************************************************************************************/

// Static variables
int drivingDeltaCounter1 = 0;
int drivingDeltaCounter2 = 0;
bool tempRunAwayAlarm1 = false;				  /**< Temperature runaway alarm for thermocouple 1 */
bool tempRunAwayAlarm2 = false;				  /**< Temperature runaway alarm for thermocouple 2 */
bool tc1Status = TC_FAULT;					  /**< Thermocouple 1 status */
bool tc2Status = TC_FAULT;					  /**< Thermocouple 2 status */
uint8_t errorFlagsMAX[] = {0, 0, 0, 0, 0, 0}; /**< Error flags for MAX31855 thermocouple sensor */
int16_t temp1;								  /**< Current temperature reading from thermocouple 1 */
int16_t temp2;								  /**< Current temperature reading from thermocouple 2 */
bool sdGood = false;						  /**< SD card status */
String currentFileName = "";				  /**< Current file name for data logging */
File dataFile;								  /**< Data file object for logging */
static unsigned long lastFlushTime = 0;
const unsigned long flushInterval = 5000; // Flush every 5 seconds

// Process Varaibles
unsigned long activeTime = 0;
unsigned long preheatingTime = 0;
unsigned long heatingTime = 0;

unsigned long preheatTransitionStartTime = 0; // Tracks when both temps first meet preheating criteria

unsigned long currentMillis = 0;
unsigned long lastMillis = 0;

unsigned long cycleStart1 = 0;
unsigned long cycleStart2 = 0;

unsigned long lastThermalRunawayCheck = 0; // Tracks the last thermal runaway check time

bool relay1ManualOff = false;
bool relay2ManualOff = false;

// PID Process Parameters
double Setpoint, Input1, Output1, Input2, Output2;

// Timing variable for the serial print interval, for serial command mode
#ifdef _SERIALCMD_
unsigned long lastSerialPrint = 0;
#endif /* _SERIALCMD_ */

// LCD State and Event variables
#ifdef _LCDGUI_
uint8_t uEvent;				   /**< Current pending user event */
uint8_t uToggle;			   /**< Current user toggle */
int16_t encLastPos, encNewPos; /**< Encoder position variables */
unsigned long lastActiveTime;
#endif /* _LCDGUI_ */

// Structures and objects
progData pData; /**< Program operating data */

ProcessStateWrapper currentProcessState(INACTIVE_PROCESS);

ActiveProcessSubstateWrapper currentActiveProcessSubstate(UNKNOWN);

const char *getCurrentProcessState()
{
	return currentProcessState.toChar();
}

const char *getCurrentActiveProcessSubstate()
{
	return currentActiveProcessSubstate.toChar();
}

const char *getStateInfo()
{
	static char buffer[16];
	unsigned long output = static_cast<unsigned long>(Output1) * 0.5 + static_cast<unsigned long>(Output2) * 0.5;

	if (strcmp(getCurrentProcessState(), "ACTIVE") == 0)
	{
		// Concatenate first two letters, setTemp, "C", and output without spaces
		sprintf(buffer, "%dC %lu", pData.setTemp, output);
	}
	else
	{
		// For other states, just show the first two letters of the state
		sprintf(buffer, "%s", getCurrentProcessState());
	}
	return buffer;
}

const char *getStatusInfo()
{
	static char buffer[10]; // Buffer to hold the formatted string

	if (strcmp(getCurrentProcessState(), "ACTIVE") == 0)
	{
		// Ensure heatingDuration is treated accurately as milliseconds in integer math
		unsigned long heatingDurationMillis = static_cast<unsigned long>(pData.heatingDuration);
		unsigned long remainingTime = heatingDurationMillis - heatingTime; // Remaining time in milliseconds
		unsigned long hours = remainingTime / (3600000UL);				   // 1000 * 60 * 60
		unsigned long minutes = (remainingTime % (3600000UL)) / (60000UL); // (1000 * 60)
		unsigned long percentCompletion = (heatingTime * 100UL) / heatingDurationMillis;

		sprintf(buffer, "%lu%% %02lu:%02lu", percentCompletion, hours, minutes); // Format as "XX% HH:MM"
	}
	else
	{
		strcpy(buffer, "---% --:--"); // Set the string for non-ACTIVE states
	}

	return buffer;
}

const char *getDurationInfo()
{
	static char buffer[10];

	// Ensure heatingDuration is treated accurately as milliseconds in integer math
	unsigned long heatingDurationMillis = static_cast<unsigned long>(pData.heatingDuration);
	unsigned long hours = heatingDurationMillis / (3600000UL);				   // 1000 * 60 * 60
	unsigned long minutes = (heatingDurationMillis % (3600000UL)) / (60000UL); // (1000 * 60)

	sprintf(buffer, "%02lu:%02lu", hours, minutes); // Format as "XX% HH:MM"
	return buffer;
}

const char *getSetTempInfo()
{
	static char buffer[20];

	// Get the current set temperature from pData structure
	unsigned int setTemp = pData.setTemp;

	sprintf(buffer, "Set Temp: %u C", setTemp); // Format as "Set Temp: ### C"
	return buffer;
}

Adafruit_MAX31855 thermocouple1(PIN_TC_CLK, PIN_TC_CS1, PIN_TC_DO); /**< Thermocouple 1 object */
Adafruit_MAX31855 thermocouple2(PIN_TC_CLK, PIN_TC_CS2, PIN_TC_DO); /**< Thermocouple 2 object */

#ifdef _LCDGUI_
ClickEncoder *encoder;				/**< Encoder object */
LiquidCrystal_I2C lcd(0x27, 16, 2); /**< LCD display object */

// Declare strings to store in flash memory
const char fastResearchText[] PROGMEM = "FAST Research";
const char oschssPressText[] PROGMEM = "OSCHSS Press";
const char versionText[] PROGMEM = "Version:";
const char versionNumberText[] PROGMEM = "1.1.0";
const char licenseText[] PROGMEM = "License:";
const char gplv3FreeText[] PROGMEM = "GPLv3 \"FREE\"";

// SETUP DISPLAYS
LiquidLine setup_line1(0, 0, fastResearchText);
LiquidLine setup_line2(0, 1, oschssPressText);
LiquidLine setup_line3(0, 0, versionText);
LiquidLine setup_line4(0, 1, versionNumberText);
LiquidLine setup_line5(0, 0, licenseText);
LiquidLine setup_line6(0, 1, gplv3FreeText);
LiquidScreen setup_screenA(setup_line1, setup_line2);
LiquidScreen setup_screenB(setup_line3, setup_line4);
LiquidScreen setup_screenC(setup_line5, setup_line6);
LiquidMenu setup_menu(lcd, setup_screenA, setup_screenB, setup_screenC);

// MAIN DISPLAY MACHINE STATUS
LiquidLine machine_status_line1(0, 0, "1:", temp1, "C ", getStateInfo);
LiquidLine machine_status_line2(0, 1, "2:", temp2, "C ", getStatusInfo);
LiquidScreen machine_status_screenA(machine_status_line1, machine_status_line2);
LiquidMenu machine_status_menu(lcd, machine_status_screenA);

const char statusScreenText[] PROGMEM = "/Status Screen";
const char durationText[] PROGMEM = "Duration: ";
const char activateText[] PROGMEM = "Activate";
const char stopText[] PROGMEM = "Stop";

// MAIN DISPLAY MAIN MENU
LiquidLine main_line0(0, 0, statusScreenText);
LiquidLine main_line1(0, 1, getSetTempInfo);
LiquidLine main_line2(0, 1, durationText, getDurationInfo);
LiquidLine main_line3(0, 1, activateText);
LiquidLine main_line4(0, 1, stopText);
LiquidScreen main_screen;

LiquidMenu main_menu(lcd, main_screen);

// Menu system
LiquidSystem menu_system(setup_menu, machine_status_menu, main_menu);

void setupLcdLines()
{
	setup_line1.set_asProgmem(1);
	setup_line2.set_asProgmem(1);
	setup_line3.set_asProgmem(1);
	setup_line4.set_asProgmem(1);
	setup_line5.set_asProgmem(1);
	setup_line6.set_asProgmem(1);

	machine_status_line1.attach_function(FUNC_ENTER_MENU, goto_main_menu);
	machine_status_line1.set_focusPosition(Position::CUSTOM, 16, 0);

	machine_status_line2.attach_function(FUNC_ENTER_MENU, goto_main_menu);
	machine_status_line2.set_focusPosition(Position::CUSTOM, 16, 0);

	// Add lines and attach functions to the main menu
	main_line0.set_asProgmem(1);
	main_line1.set_asProgmem(1);
	main_line2.set_asProgmem(1);
	main_line3.set_asProgmem(1);
	main_line4.set_asProgmem(1);
	main_screen.add_line(main_line0);
	main_screen.add_line(main_line1);
	main_screen.add_line(main_line2);
	main_screen.add_line(main_line3);
	main_screen.add_line(main_line4);
	main_screen.set_displayLineCount(2);
	main_line0.attach_function(FUNC_ENTER_MENU, goto_machine_status_menu);
	main_line1.attach_function(FUNC_ENTER_MENU, toggle_function);
	main_line1.attach_function(FUNC_DECRT_PDATA, decrt_pdata_setTemp);
	main_line1.attach_function(FUNC_INCRT_PDATA, incrt_pdata_setTemp);
	main_line2.attach_function(FUNC_ENTER_MENU, toggle_function);
	main_line2.attach_function(FUNC_DECRT_PDATA, decrt_pdata_heatingDuration);
	main_line2.attach_function(FUNC_INCRT_PDATA, incrt_pdata_heatingDuration);
	main_line3.attach_function(FUNC_ENTER_MENU, activate_proc);
	main_line4.attach_function(FUNC_ENTER_MENU, deactivate_proc);
}

void timerIsr()
{
	encoder->service();
}

#endif /* _LCDGUI_ */

// PID object setup for both thermocouples
// PID myPID1(&Input1, &Output1, &Setpoint, consKp, consKi, consKd, P_ON_M, DIRECT);
PID myPID1(&Input1, &Output1, &Setpoint, DEF_KP / MILLI_UNIT, DEF_KI / MILLI_UNIT, DEF_KD / MILLI_UNIT, DIRECT); /**< PID1 object gets input from thermocouple 1 and ouputs to relay 1*/

PID myPID2(&Input2, &Output2, &Setpoint, DEF_KP / MILLI_UNIT, DEF_KI / MILLI_UNIT, DEF_KD / MILLI_UNIT, DIRECT); /**< PID2 object gets input from thermocouple 2 and ouputs to relay 2*/

// ------------------------------------------------------
// SETUP -------------------------------------------------
// ------------------------------------------------------

/**
 * @brief Prepares MCU for startup by clearing reset flags and disabling the watchdog timer.
 *
 * Executes in the .init3 section during AVR startup, ensuring a clean state by:
 * - Clearing MCU Status Register (MCUSR) to remove any reset flags.
 * - Disabling the watchdog timer to prevent unintended resets at startup.
 *
 * Utilizes `__attribute__((naked))` to avoid standard prologue/epilogue and
 * `__attribute__((section(".init3")))` for early execution before main().
 */
void reset_mcusr(void) __attribute__((naked)) __attribute__((section(".init3")));
void reset_mcusr(void)
{
	MCUSR = 0;
	wdt_disable();
}

// Setup helpers
bool thermocoupleSetup(Adafruit_MAX31855 &thermocouple)
{
	// Initializing the setup error flag
	bool tcInitFlag = false;

	// Check if thermocouple initialization fails
	if (!thermocouple.begin())
	{
		tcInitFlag = false;
	}
	else
	{
		tcInitFlag = true; // replace with macro
	}
	return tcInitFlag;
}

// Setup Main
void setup()
{
#ifdef _LCDGUI_
	// This needs to happen before the delay to allow the Timer1 to be set up before the
	// user needs to use it to possibly enter the system menu.
	encoder = new ClickEncoder(PIN_ENC_DT, PIN_ENC_CLK, PIN_ENC_SW, 4);

	Timer1.initialize(1 * MILLI_UNIT); // 1* MILLI_UNIT = 1,000ms = 1s
	Timer1.attachInterrupt(timerIsr);

	// This is the I2C LCD object initialization.
	lcd.init();
	lcd.backlight();

	// Load lines from PROGMEM, add lines, attach functions
	setupLcdLines();

	// Menu initialization.
	menu_system.update();
	menu_system.change_menu(setup_menu);

	unsigned long setupMenuMillis = 0;
	const long setupMenuInterval = 500; // interval at which to change screen (milliseconds)

	// This timing loop also the user the physical time for entering eeprom reset on GUI or to click and open serial monitor on PC
	// Display the setup screens
	for (int i = 0; i < 3; i++)
	{
		setupMenuMillis = millis();
		while (millis() - setupMenuMillis < setupMenuInterval)
		{
		}
		if (i != 0)
		{
			setup_menu.next_screen();
		}
	}
#endif /* _LCDGUI_ */

	// Initialize thermocouple pins
	pinMode(PIN_TC_CS1, OUTPUT);
	tc1Status = thermocoupleSetup(thermocouple1);

	pinMode(PIN_TC_CS2, OUTPUT);
	tc2Status = thermocoupleSetup(thermocouple2);

	// Set SSR pins as output
	pinMode(PIN_SSR1, OUTPUT);
	pinMode(PIN_SSR2, OUTPUT);
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
void loop()
{
	readCheckTemp();

#ifdef _LCDGUI_
	encoderEvent();
	updateLcdGui();
	checkSleep();
#endif

	logSD();

#ifdef _SERIALCMD_
	handleSerialCommands();
	printSerialData();
#endif

	updateEeprom();

	// Main process control
	// Update the current time in milliseconds
	currentMillis = millis();

	// Check if enough time has passed for the next process control loop
	if (currentMillis - lastMillis >= pData.processInterval)
	{
		switch (currentProcessState.getState())
		{
		case ACTIVE_PROCESS:
			thermalRunawayCheck();

			openNewFileIfNeeded();

			// Only run PID and slowPWM if activeProcess is true
			Setpoint = (double)pData.setTemp;
			dynamicTuning();

			Input1 = (double)temp1;
			myPID1.Compute();
			Input2 = (double)temp2;
			myPID2.Compute();

			if (relay1ManualOff)
			{
				Output1 = 0; // Set Output1 to zero if relay1ManualOff is true
			}

			if (relay2ManualOff)
			{
				Output2 = 0; // Set Output2 to zero if relay2ManualOff is true
			}

			slowPWM(PIN_SSR1, cycleStart1, pData.controlPeriod, Output1);
			slowPWM(PIN_SSR2, cycleStart2, pData.controlPeriod, Output2);

			switch (currentActiveProcessSubstate.getSubstate())
			{
			case PREHEATING:
				preheatingTime += pData.processInterval;
				// Check if both temperatures are equal to or greater than setTemp - offset
				if (temp1 >= pData.setTemp - pData.preToHeatTempOffset && temp2 >= pData.setTemp - pData.preToHeatTempOffset)
				{
					// If preheatTransitionStartTime is 0, this is the first loop iteration where both temps meet the criteria
					if (preheatTransitionStartTime == 0)
					{
						preheatTransitionStartTime = currentMillis; // Start tracking time
					}
					else if (currentMillis - preheatTransitionStartTime >= pData.preToHeatHoldTime)
					{
						// Conditions have been met for 10 seconds, transition to HEATING
						currentActiveProcessSubstate.setSubstate(HEATING);
						heatingTime = 0;				// Reset or start tracking processing time
						preheatTransitionStartTime = 0; // Reset preheat start time for next use
					}
				}
				else
				{
					// If conditions are not met, reset the start time
					preheatTransitionStartTime = 0;
				}
				break;
			case HEATING:
				// Accumulate heating process duration
				heatingTime += pData.processInterval;

				// Check if process duration has been met
				if (heatingTime >= pData.heatingDuration)
				{
					currentActiveProcessSubstate.setSubstate(COOLING_DOWN);
				}
				break;
			case COOLING_DOWN:
				currentProcessState.setState(INACTIVE_PROCESS); // hardcoded at the moment, present system doesnt have active cooling
				currentActiveProcessSubstate.setSubstate(UNKNOWN);
				break;
			default:
				currentProcessState.setState(INACTIVE_PROCESS);
				break;
			}
			break;

		case INACTIVE_PROCESS:
			// If the process is not active, just read temperatures and write SSRs LOW

			Setpoint = 0;
			Output1 = 0;
			Output2 = 0;
			digitalWrite(PIN_SSR1, LOW);
			digitalWrite(PIN_SSR2, LOW);
			closeFileIfNeeded();

			break;

		case ERROR_PROCESS:

			Setpoint = 0;
			Output1 = 0;
			Output2 = 0;
			// Handle error condition, perhaps by setting SSRs to LOW and signaling error
			digitalWrite(PIN_SSR1, LOW);
			digitalWrite(PIN_SSR2, LOW);

			closeFileIfNeeded();
			// Signal error condition, e.g., by blinking an LED or sending an error message
			signalError(); // TODO

			break;

		default: // STANDBY_PROCESS & ALL ELSE

			Setpoint = 0;
			Output1 = 0;
			Output2 = 0;
			// Default action, perhaps similar to INACTIVE_PROCESS or specific safe state
			digitalWrite(PIN_SSR1, LOW);
			digitalWrite(PIN_SSR2, LOW);
			closeFileIfNeeded();

			break;
		}
		lastMillis = currentMillis;
	}
}

/* -------------------------------Signal Error----------------------------------*/
/**
 *  \brief    Signals an error condition.
 *  \remarks
 *
 */
void signalError() // TODO
{
	// Implement continuous error signaling in LCD corner and serial output
	// on first pass log dumb to SD card and serial error message. record in eeprom
}

void openNewFileIfNeeded()
{
	if (currentFileName == "")
	{
		//Serial.println("Creating new file...");
		currentFileName = createNewFile();
		//Serial.println("New file created:");
    //Serial.println(currentFileName);
		if (currentFileName != "")
		{
			dataFile = SD.open(currentFileName.c_str(), FILE_WRITE);
			if (!dataFile)
			{
				//Serial.println("Error opening file for writing.");
				currentFileName = "";
			}
		}
	}
}

void closeFileIfNeeded()
{
	if (currentFileName != "")
	{
		dataFile.close();
		currentFileName = "";
	}
}

String createNewFile()
{
	
	char fileName[13]; // "data0000.txt" + null terminator
	int fileNumber = 0;

	while (fileNumber < 10000)
	{
		snprintf(fileName, sizeof(fileName), "data%04d.txt", fileNumber);
		if (!SD.exists(fileName))
		{
			File newFile = SD.open(fileName, FILE_WRITE);
			if (newFile)
			{
				//newFile.print("MAX_flags,TRA1_Alarm,TRA2_Alarm,t1,t2,st,o1,o2,Preheat_t,Heat_t,Total_t,dt,Kp,Ki,Kd,State,Substate\n");
				newFile.close();
				return String(fileName);
			}
			else
			{
				// Serial.println("Error creating file.");
				return "";
			}
		}
		fileNumber++;
	}

	// Serial.println("Error: Too many files.");
	return "";
}


/* -------------------------------Thermal Runaway Check----------------------------------*/
/**
 *  \brief    Checks for thermal runaway.
 *  \remarks This function checks for thermal runaway by comparing the temperature readings
 *  to the setpoint plus a delta value. If the temperature readings exceed the setpoint plus
 *  the delta value for a certain number of cycles and if the output for that temperature
 *  is not issuing a zero output, a thermal runaway event is issued.
 * 	The drivingDeltaCounter holds how many cycles the temperature has been above the setpoint plus the
 *  delta value while still driving the output. If the temperature is below the setpoint plus the delta
 *  value, the counter is reset to zero. If the counter reaches the number of cycles set in the program
 *  data, a thermal runaway event is issued. drivingDeltaCounter only increases once per control period.
 */
void thermalRunawayCheck() // TODO
{

	unsigned long currentMillis = millis();
	// Check if enough time has passed for the next thermal runaway check
	if (currentMillis - lastThermalRunawayCheck >= pData.controlPeriod)
	{
		// The actual thermal runaway check logic remains the same
		if (temp1 > pData.setTemp + pData.tempRunAwayDelta || temp2 > pData.setTemp + pData.tempRunAwayDelta)
		{
			// Check if the output is not zero
			if ((int)Output1 > 0)
			{
				tempRunAwayAlarm1 = true;
				drivingDeltaCounter1++;
			}

			if ((int)Output2 > 0)
			{
				tempRunAwayAlarm2 = true;
				drivingDeltaCounter2++;
			}
		}
		else
		{
			tempRunAwayAlarm1 = false;
			tempRunAwayAlarm2 = false;
			drivingDeltaCounter1 = 0;
			drivingDeltaCounter2 = 0;
		}

		if (drivingDeltaCounter1 >= pData.tempRunAwayCycles || drivingDeltaCounter2 >= pData.tempRunAwayCycles)
		{
			currentProcessState.setState(ERROR_PROCESS);
			// Signal error condition
			signalError();
		}

		// Update the last check time
		lastThermalRunawayCheck = currentMillis;
	}
}
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

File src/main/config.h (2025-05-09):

#ifndef CONFIG_H
#define CONFIG_H

// ------------------------------
// Choose Configuration
// ------------------------------

#include "config/hardware_def.h"     // This file contains hardware-specific configurations such as pin assignments
#include "config/operating_limits.h"  // This file contains the limits for the various parameters used in the program
#include "config/timing_intervals.h" // This file contains the timing intervals for the control loop and other processes
#include "config/eeprom_settings.h"  // This file contains the EEPROM settings for the program

// ------------------------------
// Feature Enable/Disable
// ------------------------------

// Comment/uncomment the following to enable the corresponding feature

// This is for the serial command line interface
#define SERIALCMD 1

// This is for the SD card logging
#define SDCARD 1

// This is for the LCD + encoder GUI
#define GUI 1

#define REVERSE_ENCODER 1 // uncomment if your encoder is reversed

// ------------------------------
// Control Settings
// ------------------------------

// Default Heating Process Settings
#define DEF_SETPOINT 60
#define DEF_HEATING_DURATION 3000000 // 50 minutes

// PID Default Settings
#define DEF_KP 0.50
#define DEF_KI 0.05
#define DEF_KD 0.00

// PID Adaptive Settings
#define DEF_ADAPTIVE_TEMP_GAP 10
#define DEF_CP 0.10
#define DEF_CI 0.01
#define DEF_CD 0.00

// Preheat to Heat Settings
#define DEF_PRE_TO_HEAT_TEMP_OFFSET 5
#define DEF_PRE_TO_HEAT_HOLD_TIME 10 * 1000

#endif // CONFIG_H

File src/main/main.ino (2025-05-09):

#include "config.h"

#include "monitoring.h"
#include "relay.h"

#include "states.h"

#include <EEPROM.h>

#include <Adafruit_MAX31855.h>
#include <PID_v1.h>

#ifdef GUI
#include "gui.h"
#endif

#ifdef SDCARD
#include <SdFat.h>
// 1 for FAT16/FAT32, 2 for exFAT, 3 for FAT16/FAT32 and exFAT.
#define SD_FAT_TYPE 1
SdFat32 sd;
typedef File32 file_t;
file_t file;
#endif // SDCARD

#define SECOND 1000
#define MINUTE 60000

template <typename T>
void setArrayValue(T *array, int index, T value, T minVal, T maxVal, bool &isInvalid, bool clampToLimits)
{
  if (index >= 0 && index < 2)
  {
    if (value < minVal)
    {
      isInvalid = true;
      array[index] = clampToLimits ? minVal : array[index]; // Clamp to lower limit or reject
    }
    else if (value > maxVal)
    {
      isInvalid = true;
      array[index] = clampToLimits ? maxVal : array[index]; // Clamp to upper limit or reject
    }
    else
    {
      array[index] = value;
    }
  }
  else
  {
    isInvalid = true; // Index out of range
  }
}

struct ProgramData
{
  double temp[2];       // Temp is the current temperature read by the TCs
  uint8_t tempError[2]; // TempError is the error flag for the TCs
  double output[2];     // Output is the control signal for the PID controllers

  unsigned long setDuration;             // Set duration in milliseconds for active state
  unsigned long remainingDurationMillis; // Remaining duration in milliseconds for active state
  float setDurationMinutes;              // Set duration in minutes for active state
  float remainingDurationMinutes;        // Remaining duration in minutes for active state
  double setpoint[2];                    // Setpoint is the target temperature for the PID controllers
  double Kp[2];                          // Kp is the proportional gain the PID controllers
  double Ki[2];                          // Ki is the integral gain the PID controllers
  double Kd[2];                          // Kd is the derivative gain the PID controllers
  double Cp[2];                          // Cp is the proportional gain for adaptive PID
  double Ci[2];                          // Ci is the integral gain for adaptive PID
  double Cd[2];                          // Cd is the derivative gain for adaptive PID
  double adaptiveTempGap[2];             // Adaptive temperature gap for adaptive PID
  int16_t fileCount;                     // Number of log files created, used for naming
  bool sdActive;                         // Indicates that the SD card is active
  int8_t traStatus;                      // Thermal Runaway status, 0 for normal, -1 for impending, -2 for runaway
  bool isInvalid = false;                // Indicates that the last operation was invalid
  int16_t incr;                          // Increment value for encoder, used for setting values in GUI
                                         // for setpoint, Kp, Ki, Kd and other parameters dependent on 2 this leads
                                         // to them being set to the same value for all control loops in the current implementation
  // Getters
  unsigned long getSetDuration() const
  {
    return setDuration;
  }
  unsigned long getRemainingDuration() const
  {
    return remainingDurationMillis;
  }
  float getSetDurationMinutes() const
  {
    return setDuration / MINUTE;
  }
  double getSetpoint(int index) const
  {
    return setpoint[index];
  }
  double getKp(int index) const
  {
    return Kp[index];
  }
  double getKi(int index) const
  {
    return Ki[index];
  }
  double getKd(int index) const
  {
    return Kd[index];
  }
  double getCp(int index) const
  {
    return Cp[index];
  }
  double getCi(int index) const
  {
    return Ci[index];
  }
  double getCd(int index) const
  {
    return Cd[index];
  }
  double getAdaptiveTempGap(int index) const
  {
    return adaptiveTempGap[index];
  }
  int16_t getFileCount() const
  {
    return fileCount;
  }
  bool isSdActive() const
  {
    return sdActive;
  }
  int8_t getTraStatus() const
  {
    return traStatus;
  }
  bool getIsInvalid() const
  {
    return isInvalid;
  }

  // Setters for array elements using the template with clamping option
  void setSetpoint(int index, double value, bool clampToLimits = false)
  {
    setArrayValue(setpoint, index, value, static_cast<double>(MIN_TEMP), static_cast<double>(MAX_TEMP), isInvalid, clampToLimits);
  }

  void setKp(int index, double value, bool clampToLimits = false)
  {
    setArrayValue(Kp, index, value, static_cast<double>(MIN_KP), static_cast<double>(MAX_KP), isInvalid, clampToLimits);
  }

  void setKi(int index, double value, bool clampToLimits = false)
  {
    setArrayValue(Ki, index, value, static_cast<double>(MIN_KI), static_cast<double>(MAX_KI), isInvalid, clampToLimits);
  }

  void setKd(int index, double value, bool clampToLimits = false)
  {
    setArrayValue(Kd, index, value, static_cast<double>(MIN_KD), static_cast<double>(MAX_KD), isInvalid, clampToLimits);
  }

  void setCp(int index, double value, bool clampToLimits = false)
  {
    setArrayValue(Cp, index, value, static_cast<double>(MIN_CP), static_cast<double>(MAX_CP), isInvalid, clampToLimits);
  }

  void setCi(int index, double value, bool clampToLimits = false)
  {
    setArrayValue(Ci, index, value, static_cast<double>(MIN_CI), static_cast<double>(MAX_CI), isInvalid, clampToLimits);
  }

  void setCd(int index, double value, bool clampToLimits = false)
  {
    setArrayValue(Cd, index, value, static_cast<double>(MIN_CD), static_cast<double>(MAX_CD), isInvalid, clampToLimits);
  }

  void setAdaptiveTempGap(int index, double value, bool clampToLimits = false)
  {
    setArrayValue(adaptiveTempGap, index, value, static_cast<double>(0), static_cast<double>(MAX_TEMP), isInvalid, clampToLimits);
  }

  void setSetDuration(unsigned long value, bool clampToLimits = false)
  {
    if (value < MIN_SET_DURATION)
    {
      isInvalid = true;
      setDuration = clampToLimits ? MIN_SET_DURATION : setDuration; // Clamp to lower limit or reject
    }
    else if (value > MAX_SET_DURATION)
    {
      isInvalid = true;
      setDuration = clampToLimits ? MAX_SET_DURATION : setDuration; // Clamp to upper limit or reject
    }
    else
    {
      setDuration = value; // Valid value within range
    }
    setDurationMinutes = setDuration / MINUTE;
  }

  void setFileCount(int16_t value)
  {
    fileCount = value;
  }

  void setSdActive(bool value)
  {
    sdActive = value;
  }

  void setTraStatus(int8_t value)
  {
    traStatus = value;
  }
};

ProgramData pData;

// Initialize the thermocouples
Adafruit_MAX31855 thermocouples[2] = {
    Adafruit_MAX31855(PIN_TC_CLK, PIN_TC_CS1, PIN_TC_DO),
    Adafruit_MAX31855(PIN_TC_CLK, PIN_TC_CS2, PIN_TC_DO)};

// PID
PID pidControllers[2] = {PID(&pData.temp[0], &pData.output[0], &pData.setpoint[0], DEF_KP, DEF_KI, DEF_KD, P_ON_M, DIRECT),
                         PID(&pData.temp[1], &pData.output[1], &pData.setpoint[1], DEF_KP, DEF_KI, DEF_KD, P_ON_M, DIRECT)};
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

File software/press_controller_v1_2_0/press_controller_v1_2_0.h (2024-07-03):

#ifndef _PRESS_CONTROL_v1_2_0_H
#define _PRESS_CONTROL_v1_2_0_H

/***************************************************************************************************
 *  \par        Press Controller - Header.
 *
 *  \par        Details
 *  \par
 *              Press Controller v1 Firmware.
 *              This is the Arduino Code for the Open Source Cold Hot Scientific Sheet Press.
 *  \par
 *              You need to have the following libraries installed in your Arduino IDE:
 *               - [leave blank fill later with all the libraries]
 *
 *              This release has been tested with the following library versions:
 *              [lib]  Vxx.yy.zz
 *
 *  \file       press_controller_v1_1_0.h
 *  \author     Cameron K. Brooks
 *  \authors    Adapted from Arduino_Spot_Welder_V4_0_2.ino <https://github.com/KaeptnBalu/Arduino_Spot_Welder_V4> by Marc Schönfleisch <http://malectrics.eu/>
 *  \version    1.1.0
 *  \date       Mar 2024
 *  \copyright  Copyright(c)2024 Marc Schönfleisch <info@malectrics.eu>. All right reserved.
 *  \copyright  Copyright(c) 2024 Cameron K. Brooks <cambrooks3393@gmail.com>.
 *
 *  \par        Changelog
 *  \li         2024-MM-DD  -  Initial release
 *
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
 *
 ***********************************************************************************************/

// Most of these macros define strings that appear on the splash screen during set up
// (each line of the splash screen is limited to 16 characters)
#define _DEVICENAME_ "OSCHSSP"
#define _PROGNAME_ "Press Controller"
#define _AUTHOR_ "CKB - MCW - JMP"
#define _VERSION_MAJOR_ 1
#define _VERSION_MINOR_ 1
#define _REVISION_ 0
#define _COPYRIGHT_ "2024"
#define _LICENSE_ "GNU V3 " FREE ""
#define _ORGANIZATION_ "FAST Research"
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

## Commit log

2023-09-30 Delete electrical-design directory
    Added gitignore, will repush
    [05_042340-a.csv, 08_042340a.brd, 10A Current Sensor v1.0.brd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]
2023-09-30 Delete mechanical-design directory
    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
    [0805 Chip SMD LED (2x1.2mm).step.SLDPRT, 102 RESISTOR PACK.SLDPRT, 189 RESISTOR PACK.SLDPRT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]
2023-10-08 project set up stuff and alt builds start
    [1725656.PcbLib, 1725656.SchLib, 1725656.psm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]
2023-10-08 yet more reorganizing and refactoring
    [05_042340-a.csv, 0805 Chip SMD LED (2x1.2mm).step.SLDPRT, 08_042340a.brd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]
2023-10-08 reorg anized freecad file structure
    [05_042340-a.csv, 0805 Chip SMD LED (2x1.2mm).step.SLDPRT, 08_042340a.brd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]
2023-10-09 freecad cleaning & started qelectrotech design for industrial
    [2Pos_Terminal_Block_1725656.FCStd, ACS712.FCStd, ASR-SIM240D25RW-LQ.FCStd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]
2023-10-17 coils for qet file
    [coil_matrix_calcs.csv, coil_matrix_calcs.ods]
2023-10-22 updated the electrical schematic opta
    [OSCHISP_assembly.FCStd, OSCHISP_electrical_BOM_opta_v1.0.xlsx, OSCHISP_electrical_BOM_opta_v1.1.xlsx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]
2023-10-24 alternative suppliers
    [OSCHISP_electrical_BOM_opta_v1.1.xlsx, OSCHSSP_electrical_BOM_adafruit_v1.0.xlsx, OSCHSSP_electrical_BOM_seeed_v1.0.xlsx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]
2023-10-24 sourcing components
    [OSCHISP_electrical_BOM_opta_v1.1.xlsx, OSCHSSP_electrical_BOM_adafruit_v1.0.xlsx, OSCHSSP_electrical_BOM_reprappress_v1.0.xlsx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]
2023-11-01 separated industrial into own repo
    [OSCHISP_assembly.FCStd, OSCHISP_electrical_BOM_discrete_v1.0.xlsx, OSCHISP_electrical_BOM_opta_v1.1.xlsx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]
2023-11-02 enabled lfs for step and stl files
    [DG308-2.54-02P-14-00AH.STEP, DG308-2.54-03P-14-00AH.STEP, DG308-2.54-04P-14-00AH.STEP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]
2023-11-09 added flow diagram mermaid js in jupyter
    [OSCHSSP_Mini_Enclosure_v1.1-Base.3mf, OSCHSSP_Mini_Enclosure_v1.1-Bracket_Pieces.3mf, OSCHSSP_Mini_Enclosure_v1.1-Top.3mf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]
2023-11-12 added algo charts
    [OSCHSSP_printable_enclosure_moratus_v1.1-base.3mf, OSCHSSP_printable_enclosure_moratus_v1.1-base.stl]
2023-11-12 Upload New File
    [DIN_Rail_Cable_Clamp.stl]
2023-12-05 updated the core software builds and added algorithm charts
    [OSCHSSP_Mini_Enclosure_v1.1-Base.3mf, OSCHSSP_Mini_Enclosure_v1.1-Bracket_Pieces.3mf, OSCHSSP_Mini_Enclosure_v1.1-Top.3mf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]
2024-01-26 initial commit of prudentia
    [OSCHSSP_printable_enclosure_prudentia_v0.2.FCStd, OSCHSSP_printable_enclosure_prudentia_v0.3.FCStd, OSCHSSP_printable_enclosure_prudentia_v0.4.FCStd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]
2024-01-26 added snap fit geo using openscad
    [OSCHSSP_printable_enclosure_prudentia_v0.5-bottom_ins.stl, OSCHSSP_printable_enclosure_prudentia_v0.5-side_wall.3mf, OSCHSSP_printable_enclosure_prudentia_v0.5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]
2024-01-28 more work on the prudentia enclosure
    [OSCHSSP_printable_enclosure_celer_v0.9.stl, OSCHSSP_printable_enclosure_celer_v0.9_base.3mf, OSCHSSP_printable_enclosure_celer_v0.9_top.3mf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]
2024-02-14 updated enclosure and added 2 DoF attachment
    [Locking_Joint_Female.stl, Locking_Joint_Male.stl, Locking_Joints_MF.3mf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]
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2024-02-23 printable enclosure for paper
    [1602 Serial LCD Module Display.STL, 1602-lcd-display.FCStd, Breaker_W28-XQ1A-14.FCStd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]
2024-02-24 updated steps & stl for paper
    [Breaker_W28-XQ1A-14.FCStd, OSCHSSP_assembly.FCStd, OSCHSSP_press_structural.FCStd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]
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2024-02-27 added file for updated electrical
    [OSCHSSP_electrical_design_prudentia_v1.0.kicad_sch, OSCHSSP_electrical_design_surculus_v1.0.fzz, OSCHSSP_electrical_design_surculus_v1.0.kicad_pcb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]
2024-02-27 cleaned up elec dir
    [OSCHSSP_electrical_design_adafruit_v1.0.kicad_pcb, OSCHSSP_electrical_design_adafruit_v1.0.kicad_sch, OSCHSSP_electrical_design_prudentia_v1.0.kicad_sch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]
2024-02-28 assembly organization for easier CAD nav
    [Breaker_W28-XQ1A-14.FCStd, PSK-5D-9.FCStd, Recepticle_C-1-1609112-3.FCStd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]
2024-02-29 updated and organized files
    [OSCHSSP_electrical_design_prudentia_v1.0.kicad_sch]
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2024-03-08 did some more clean up and gui
    [05_042340-a.csv, 0805 Chip SMD LED (2x1.2mm).step.SLDPRT, 08_042340a.brd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]
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2024-03-11 added full depth to electrical and software segmentation
    [Adafruit_MAX31855 v2.brd, Adafruit_MAX31855 v2.kicad_pcb, Adafruit_MAX31855 v2.kicad_sch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]
2024-03-11 splitting off of archives into dedicated dev archive
    [05_042340-a.csv, 0805 Chip SMD LED (2x1.2mm).step.SLDPRT, 08_042340a.brd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]
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2024-04-06 version 1.1.0 adds header var for using 1 TC, fixes to uint vars
    [press_controller_v1_1_0.h, press_controller_v1_1_0.ino]
2024-04-27 v2 of elec separating gui and improved part selection
    [1602 Serial LCD Module Display.STL, 254.STEP, Adafruit_MAX31855 v2.kicad_sch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]
2024-05-08 minor organizational changes for paper
    [Adafruit_MAX31855 v2.kicad_sch, LCD1602_I2C.kicad_sch, NanoV3.3.kicad_sch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]
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2024-08-26 Added back elec and software as submodules to new repos
    [0805 Chip SMD LED (2x1.2mm).step.SLDPRT, 102 RESISTOR PACK.SLDPRT, 1602-lcd-display.FCStd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]
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2025-02-03 added back from osf
    [Adafruit_MAX31855 v2.kicad_sch, LCD1602_I2C.kicad_sch, NanoV3.3.kicad_sch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]
2025-02-03 organized docs and moved procurement
    [Press_Elec_BOM.ods]
2025-02-11 fixed writeRelay function correct const mismatch
    [relay.cpp]
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

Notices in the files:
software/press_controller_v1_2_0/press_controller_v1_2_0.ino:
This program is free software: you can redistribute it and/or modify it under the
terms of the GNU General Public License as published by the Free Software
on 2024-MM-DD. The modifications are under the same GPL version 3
